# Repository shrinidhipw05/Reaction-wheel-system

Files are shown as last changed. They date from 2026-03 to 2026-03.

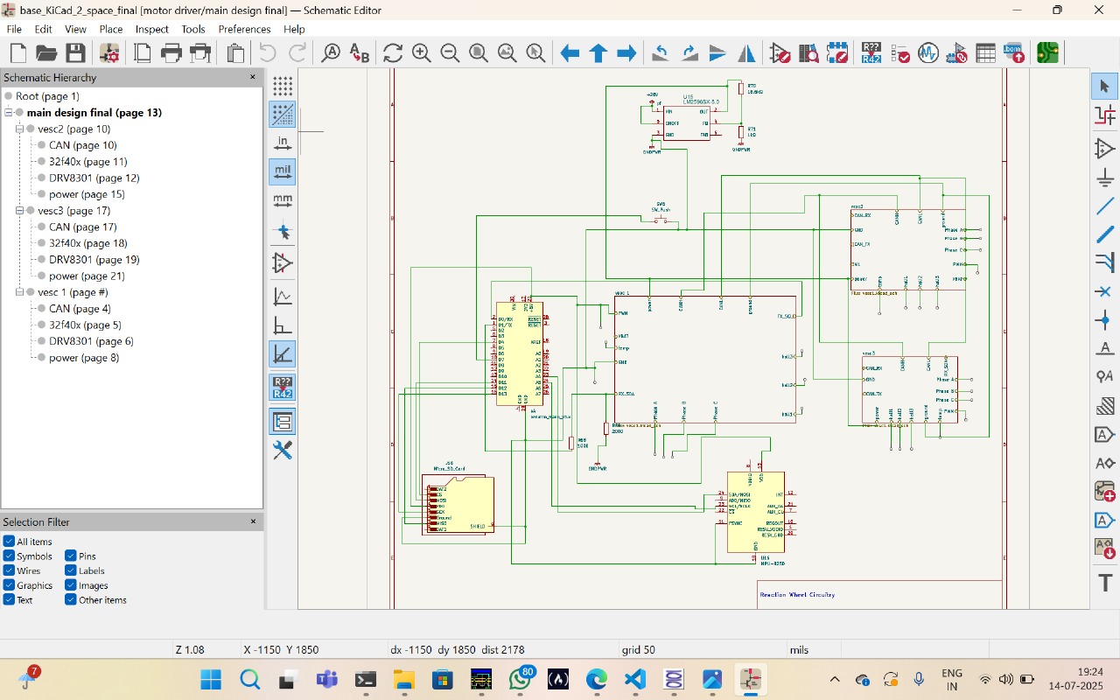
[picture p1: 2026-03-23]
docs & screenshots/Circuit& CAD screenshots/Circuit Schematic .jpg

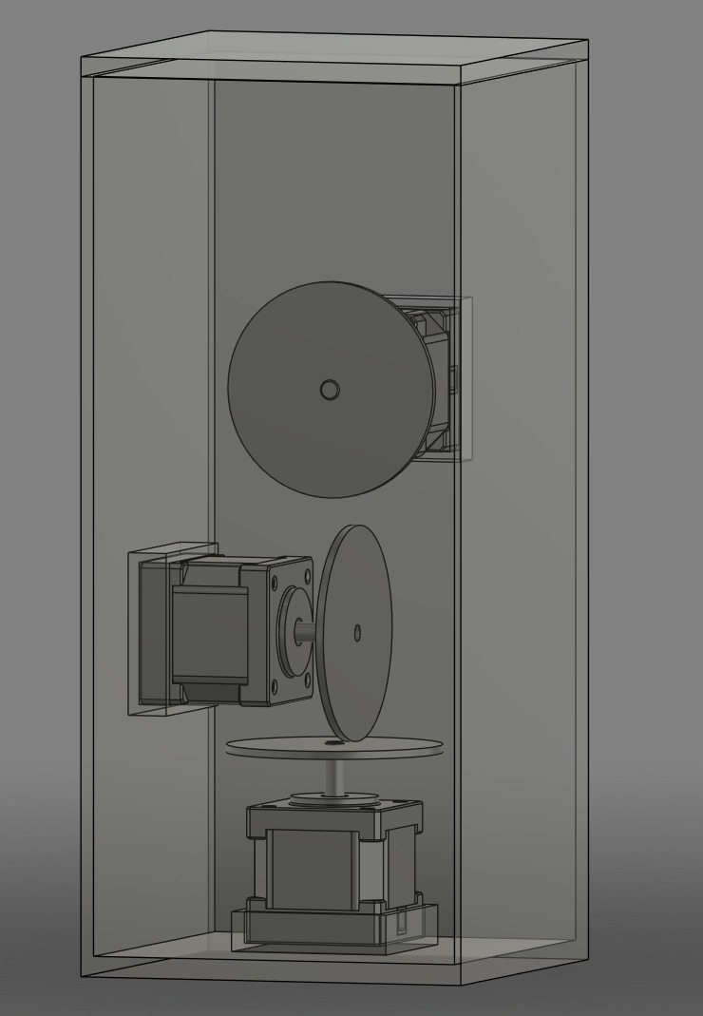
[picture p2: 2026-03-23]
docs & screenshots/Circuit& CAD screenshots/Reaction Wheel tilted front veiw-2.jpg

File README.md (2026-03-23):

# Reaction Wheel-Based CubeSat Attitude Control System

This project implements a **PID-based reaction wheel system** to stabilize the attitude of a CubeSat in space using three BLDC motors driven by VESCs. The system operates autonomously, with real-time data logging up to 24 hours, and includes safety features for thermal and electrical protection. This forms a critical part of satellite attitude control systems used in space missions.

---

## Working Principle & Features

1. **PID Control for Attitude Stabilization** &#x20;
   The system uses real-time PID-based control to stabilize a CubeSat's attitude to a predefined setpoint using three orthogonal reaction wheels (X, Y, Z axes).

2. **Triple BLDC Motor Control** &#x20;
   Each reaction wheel (BLDC motor) is controlled by an individual VESC (Electronic Speed Controller), all interfaced with a central Arduino Nano. The control logic is axis-specific:

   * X-axis: Direct UART connection to Arduino (MASTER)
   * Y, Z axes: Controlled via CAN bus communication from the master VESC

3. **Sensor Fusion Using MPU9250 + Madgwick Filter** &#x20;
   The onboard MPU9250 IMU sensor sends real-time orientation data over I2C to the Arduino Nano. Sensor fusion is performed using the Madgwick algorithm to obtain stable attitude feedback, which is compared against the target setpoint to generate PID corrections.

4. **System Behavior Under Different Conditions**

   * If the CubeSat is misaligned, PID logic drives the respective BLDC motor until the desired setpoint is reached.
   * If the motor temperature exceeds safety thresholds, the VESC automatically slows down or cuts power to prevent damage.
   * The system dynamically adjusts motor RPM in all three axes based on sensor feedback to ensure real-time orientation stability.
   * In the event of communication failure with a secondary VESC (Y or Z), the system continues operating using the X-axis (master) while logging the fault for diagnosis.

5. **VESC Configuration for Safety** &#x20;
   VESCs are configured with:

   * **Temperature Cutoff:**

     * Warning: 80°C
     * Cutoff Start: 80°C
     * Cutoff End: 100°C
   * **RPM, Voltage & Current Limits:** Predefined for safe operation
   * **Auto slowdown & shutdown:** For thermal protection

6. **CAN Communication Between VESCs**

   * VESC 0 (Master): UART enabled, CAN ID = 0, termination resistor enabled
   * VESC 1: UART disabled, CAN ID = 1, termination resistor disabled
   * VESC 2: UART disabled, CAN ID = 2, termination resistor enabled
   * All VESCs must have the following options enabled in VESC Tool:

     * Send CAN Status
     * Multiple VESCs over CAN
     * CAN Forwarding

7. **Real-Time Data Logging** &#x20;
   Data from PID loops, orientation readings, motor RPM, and temperature are logged on an SD card using a MicroSD module via SPI. This enables analysis of system performance over 24 hours.

8. **Manual CSV Reset Feature** &#x20;
   A dedicated push-button on the PCB is implemented to allow manual erasure of the current `.csv` file on the SD card and creation of a new log file. This is useful for resetting data logs between different test sessions without reprogramming or removing the SD card.

---

## Components Used

### Microcontroller

* **Arduino Nano** &#x20;
  Central controller executing PID logic and interfacing with IMU, SD module, and VESCs.

### Sensors

* **MPU9250 (x1)** &#x20;
  9-axis IMU for real-time orientation sensing over I2C.

* **Hall Sensors (x3)** &#x20;
  Built into BLDC motors and connected to VESCs for RPM feedback.

* **NTC 10K Thermistors (x3)** &#x20;
  Glued to BLDC motors and connected to VESCs for temperature monitoring.

### Actuators

* **NEMA17 BLDC Motors (x3)** &#x20;
  Sensored brushless motors used as reaction wheels.

* **VESC (x3)** &#x20;
  Open-source motor controllers, configured via VESC Tool.

### Storage

* **Catalex MicroSD Card Module** &#x20;
  SPI-based SD card module for logging operational data.

---

## How to Setup

Each VESC must be connected to a computer via USB to configure it using the VESC Tool software.

1. **VESC Configuration (via VESC Tool)**

   * Enable:

     * Send CAN Status
     * Multiple VESCs over CAN
     * CAN Forwarding
   * Set CAN IDs:

     * VESC 0: CAN ID = 0, UART = Enabled, Termination Resistor = Enabled
     * VESC 1: CAN ID = 1, UART = Disabled, Termination Resistor = Disabled
     * VESC 2: CAN ID = 2, UART = Disabled, Termination Resistor = Enabled
   * Set Temperature Cutoffs:

     * Warning Temp: 80°C
     * Cutoff Start: 80°C
     * Cutoff End: 100°C

2. **Arduino Setup**

   * Upload the code to Arduino Nano
   * Connect MPU9250 to I2C (A4/A5)
   * Connect SD Module to SPI (D10-D13)
   * Use Software Serial (D8, D9) to connect to VESC UART (x-axis)
   * Ensure CAN communication lines are properly wired between VESC 0 (master), VESC 1, and VESC 2 according to CAN protocol. Use twisted pair wiring for CANH and CANL with proper termination resistors as configured in VESC Tool.

---

## Repository Structure 

```bash
Reaction-Wheel-Controller/
├── src_Task_3/
│   └── src_Task_3.ino                        # Arduino control code
├── README.md                                 # Project documentation
├── hardware_Task_1&2/
│   ├── kicad files opening instructions.pdf  # steps to get kicad_sch & kicad_pcb & kicad_pro files
│   ├── Reaction Wheels Design.step           # CAD model for simulation
│   └── Task-2  .pro , .sch , _pcb files.zip  # zip folder of kicad files
├── Power_Task2_doc/
│   └── Explanation pdf.pdf                   # Power circuit explanation
├── challenges/ 
│   └── challenges.txt                        # Design/implementation difficulties
└── docs & screenshots/
    └── Circuit& CAD screenshots/             # image folders and pdf related to project
    └── VESC_TOOL_Screenshots/
    └── README.pdf                                   
```

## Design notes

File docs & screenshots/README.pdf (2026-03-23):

# Reaction Wheel-Based CubeSat Attitude Control System

### Working Principle & Features

- PID-Based Attitude Stabilization
The CubeSat utilizes a real-time PID control algorithm to stabilize its orientation along three axes (X, Y, Z) using reaction wheels.
- Triple BLDC Motor Configuration
Each axis has a dedicated NEMA17 BLDC motor controlled via a VESC. The X-axis motor is directly managed by the Arduino Nano through UART, while Y and Z axes communicate via CAN bus.
- Sensor Fusion with MPU9250
The IMU provides 9-axis data, processed via the Madgwick filter on the Arduino Nano to derive precise orientation information for PID correction.

### Components Used

- Microcontroller
Arduino Nano acts as the central processor for PID control and communication with peripherals.
- Sensors
- MPU9250: Real-time orientation data via I2C
- Hall Sensors (x3): Built-in RPM feedback from BLDCs
- NTC 10K Thermistors (x3): Temperature monitoring on motors
- Actuators
- NEMA17 BLDC Motors (x3): Sensored motors acting as reaction wheels
- VESCs (x3): Configured motor controllers for precise control
- Storage
Catalex MicroSD Card Module logs operational data via SPI.

### System Behavior & Safety

- Attitude Correction
If misalignment is detected, PID control commands the motors until the orientation matches the setpoint.
- Fault Handling
In case of failure in Y or Z axis VESCs, the X-axis motor continues functioning. Faults

1.

1.

1.

are logged for diagnosis.

- Thermal Protection
VESCs automatically slow down or shut off motors when temperature thresholds are reached:
- Warning: 80°C
- Cutoff Start: 80°C
- Cutoff End: 100°C
- RPM, Voltage & Current Limiting
VESC parameters are configured to prevent overdraw and ensure system safety.

### Communication & Logging

- CAN Communication Setup
- VESC 0 (Master): CAN ID = 0, UART Enabled, Termination = Enabled
- VESC 1: CAN ID = 1, UART Disabled, Termination = Disabled
- VESC 2: CAN ID = 2, UART Disabled, Termination = Enabled

All VESCs have: Send CAN Status, Multiple VESCs, and CAN Forwarding enabled in VESC Tool.

- Real-Time Data Logging
Orientation, PID output, RPM, and temperature are logged for up to 24 hours.
- Manual CSV Reset
A push-button resets the .csv log without reprogramming the SD card.

### Setup Instructions

- Arduino Nano Setup
- Upload PID control firmware
- Connect MPU9250 via I2C (A4/A5)
- Connect SD Module via SPI (D10-D13)
- Connect VESC UART via Software Serial (D8/D9)
- VESC Configuration via USB & VESC Tool
- Set CAN IDs and termination resistors
- Enable CAN features
- Set temperature cutoffs and current/RPM limits
- Wiring Notes
Ensure CANH and CANL lines are twisted pairs with proper termination. Use shielded wires for high-current and signal lines.

1.

1.

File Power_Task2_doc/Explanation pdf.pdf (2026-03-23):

### Reaction Wheel Project: Component Justification, Layout Design, and Power Optimization

### 1. Justification for Choice of Components

NEMA17 BLDC Motor
- Compact size and high torque-to-inertia ratio for precise torque control.
- Supports accurate angular momentum adjustment in small satellites.
- Preferred over brushed DC motors due to better efficiency, longer lifespan, and smoother control without brush wear issues.

VESC (Vedder Electronic Speed Controller)
- Features bi-direction control of BLDC.
- Can be configured via VESC tool, and supports FOC (field oriented control).
- Offers fine torque/speed control and supports UART/CAN with telemetry.

Arduino Nano Microcontroller
- Low-power and compact with sufficient control and communication features.
- Interfaces easily with IMU, VESCs and SD module.

MPU9250 (IMU Sensor)
- Integrates 9-DOF(degrees of freedom) sensing in a low-power chip.
- Provides accurate real-time orientation data.

LM2596 Buck Converter
- High-efficiency step-down converter for voltage regulation.
- Powers both logic and motor components with stability.

### 2. Layout Arrangement

MT60 connectors are used for BLDC phase wires and XT60 for 28V DC input. These connectors ensure secure, high-current connections, suitable for compact and reliable system integration, and can withstand rugged space environment.

Mechanical Layout
- Flywheel Placement: Mounted on the BLDC motor shaft and aligned with the center of mass of the system to minimize unwanted torques.
- Motor and ESC Positioning: VESCs/PCB are placed close to motors to reduce phase wire length.
- Controller and IMU: Positioned near the system center to reduce vibrations and increase accuracy of orientation measurements.

Electrical Layout
- Power Lines: Short, thick wires for power delivery; twisted pairs used to minimize inductive noise.
- PCB Integration: All connections are routed through the custom PCB except for the BLDC motor wires and input DC wires, which are directly soldered onto the PCB for improved current handling and mechanical reliability.

### 3. Strategies for Low Power Consumption

Physical connectors such as MT60 and XT60 also contribute to power efficiency by reducing contact resistance and improving current transfer, thus minimizing power losses at connection points.

Motor Control Efficiency
- Use of Field Oriented Control (FOC) on the VESC to reduce power loss and improve motor efficiency.
- RPM, input voltage, input current, and motor current limits are configured via VESC Tool to prevent excessive power draw and ensure energy-efficient operation.
- The motor automatically slows down at defined temperature cutoff and shuts off at endpoint values set through the VESC Tool, protecting the system and conserving power during thermal stress.

Efficient Power Conversion
- LM2596 chosen for its high-efficiency conversion (up to 85%).
- Voltage levels chosen to match component requirements precisely, avoiding unnecessary conversion losses.

Minimized Communication Overhead
- Use of UART/CAN instead of high-power wireless communication modules.
- Efficient, lightweight data protocols for communication between Arduino and VESC.

THIS APPROACH ENSURES THAT THE REACTION WHEEL SYSTEM REMAINS COMPACT, EFFICIENT, AND RELIABLE—KEY CHARACTERISTICS FOR SPACE-CONSTRAINED, POWER-LIMITED ENVIRONMENTS LIKE SATELLITES OR SPACECRAFT.

NEXT PAGE CONTAINS THE REACTION WHEEL BLOCK DIAGRAM INDICATING COMMUNICATION TYPE AND POWER DISTRIBUTION AMONG THE COMPONENTS OF THE PCB.

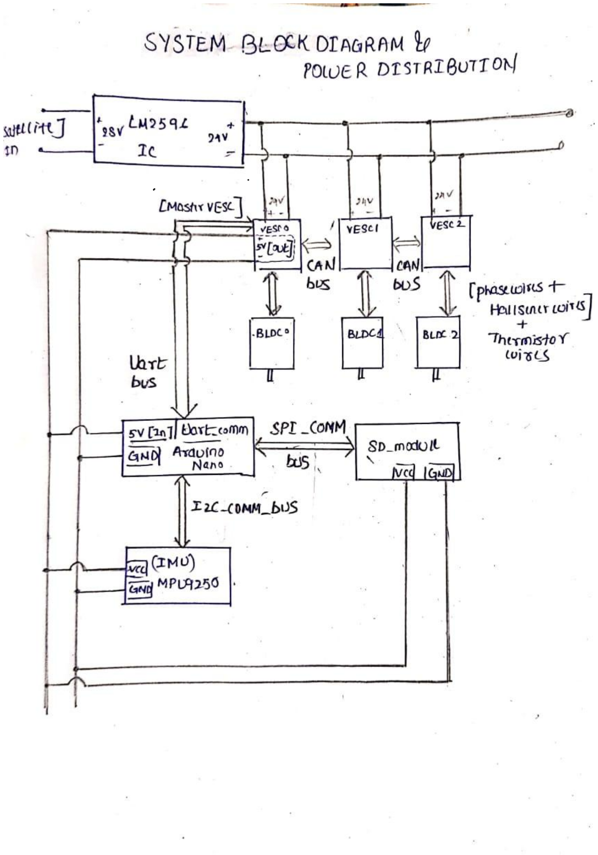
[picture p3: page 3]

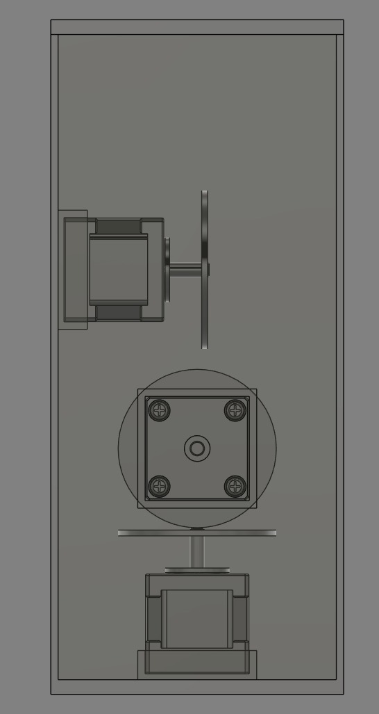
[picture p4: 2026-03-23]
docs & screenshots/Circuit& CAD screenshots/Reaction Wheel Side View.jpg

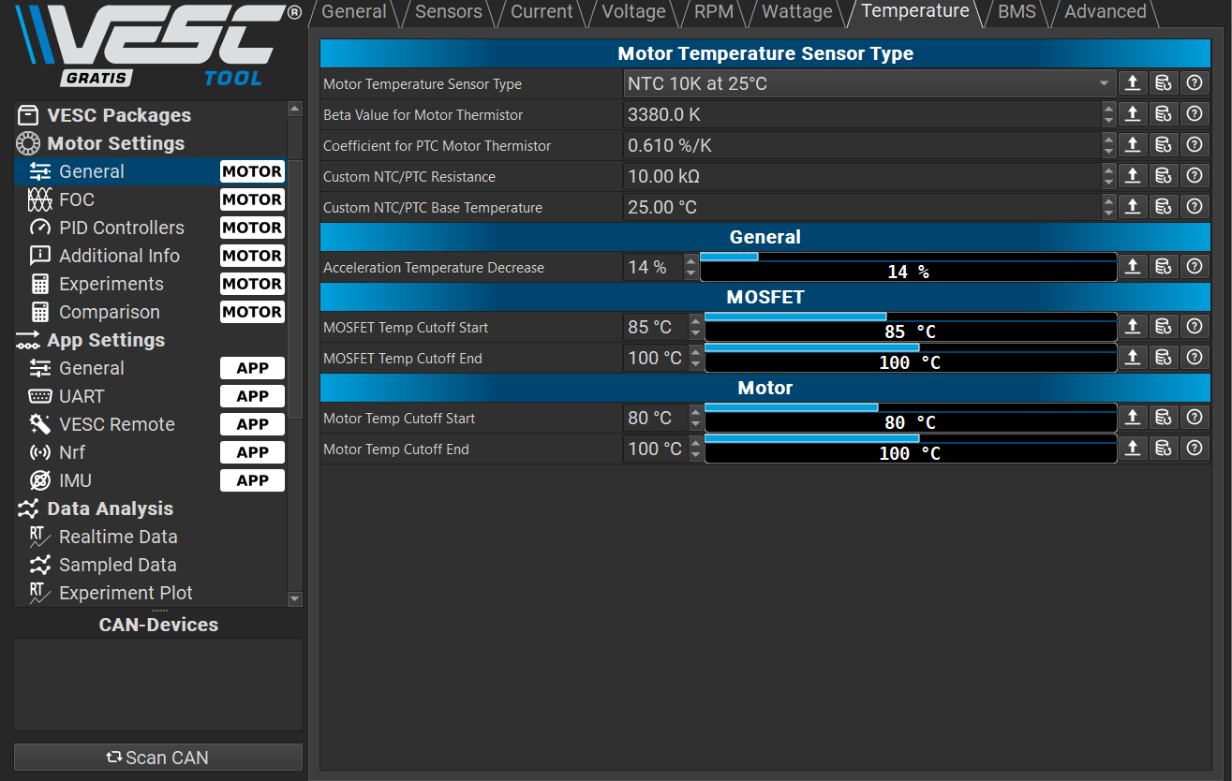
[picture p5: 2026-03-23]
docs & screenshots/VESC_TOOL_Screenshots/vesc_motor_temperature.png

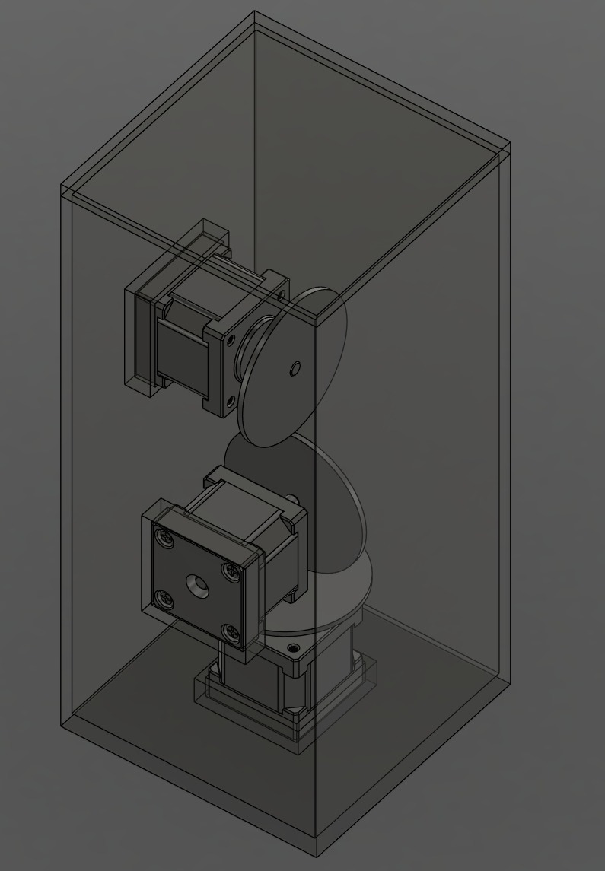
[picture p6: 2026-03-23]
docs & screenshots/Circuit& CAD screenshots/Reacition Wheel Isometric view.jpg

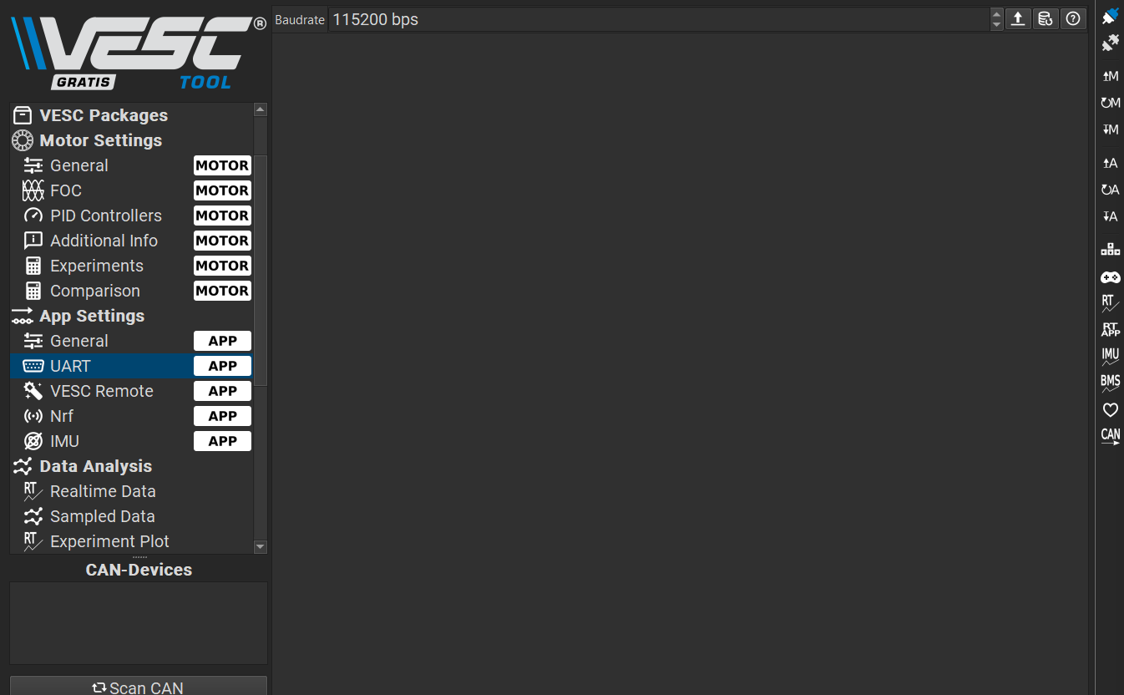
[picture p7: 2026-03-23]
docs & screenshots/VESC_TOOL_Screenshots/vesc_app_Uart.png

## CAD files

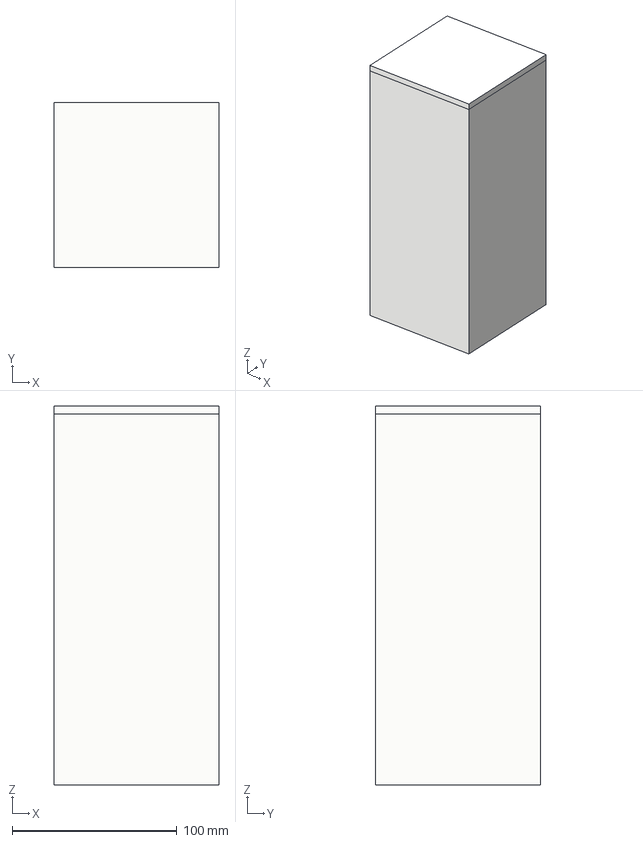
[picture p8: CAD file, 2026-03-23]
hardware_Task 1&2/Reaction Wheels Design.step
100.0 x 100.0 x 230.0 mm
Satellite Housing
6627T38_Stepper Motor x 3
Wheel1
Wheel2
Wheel3
Housing Lid

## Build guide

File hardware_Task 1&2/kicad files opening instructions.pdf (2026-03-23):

- The main kicad files for this project are named as:
1. motor driver.kicad_pro
2. motor driver.kicad_sch
3. motor driver.kicad_pcb
- The KICAD file of this project includes, custom library and is hierarchal with respect to schematic file, hence the folder contains the multiple files with the main project’s kicad files.
- To access above main files:
1. Unzip the folder-“ Task-2 .pro , .sch , _pcb files” and open it.
2. the folder contains a single subfolder, open that.
3. after opening:

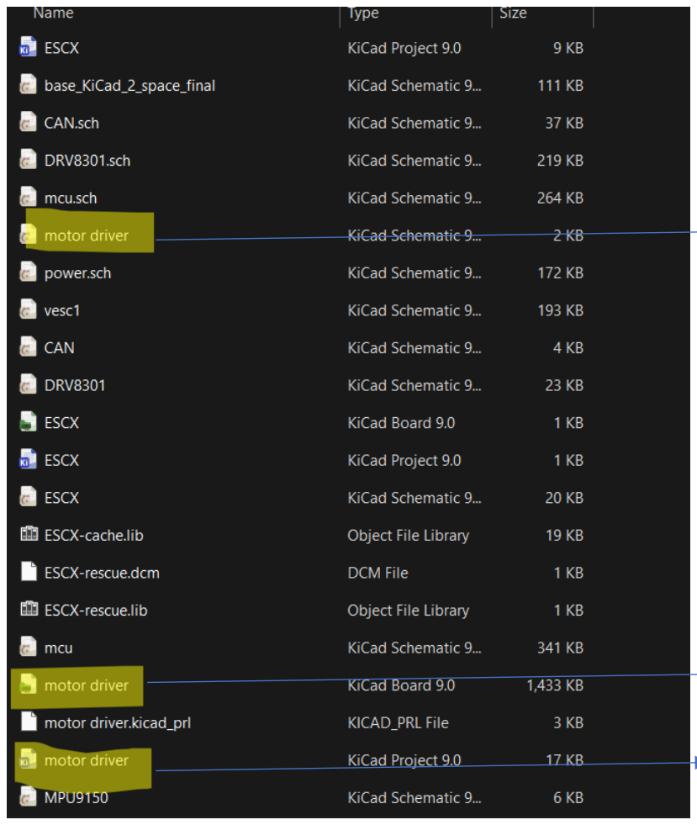
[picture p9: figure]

Click on this to view the circuit schematic (motor driver.kicad_sch)

Click on this to view the circuit pcb footprint (motor driver .kicad_pcb)

Click on this to view the circuit kicad project file (includes all files, motor driver.kicad_pro)

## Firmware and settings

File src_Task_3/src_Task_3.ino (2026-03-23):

//include all mandatory external modules for code's operation 
#include <VescUart.h>
#include <Wire.h>
#include <MPU9250.h>
#include <MadgwickAHRS.h>
#include <SoftwareSerial.h>
#include <SD.h>

// MPU9250 and Madgwick filter setup.
MPU9250 mpu;
Madgwick filter;
float roll = 0.0, pitch = 0.0, yaw = 0.0;

// VESC and Uart communication setup.
VescUart vesc;
#define RX_PIN 10
#define TX_PIN 11
SoftwareSerial vescSerial(RX_PIN, TX_PIN);

// SD Card ,logfile setup
#define SD_CS 4  //declaring chip select for the arduino .
File logfile;

// Manual data flushing : Reset Button for SD file (active LOW).
#define RESET_BUTTON 7

// PID parameters
float kp = 1.2f, ki = 0.5f, kd = 0.1f;
float setpoint[3] = {0.0f, 0.0f, 0.0f}; // Roll, Pitch, Yaw (target).
float integral[3] = {0.0f, 0.0f, 0.0f}, prev_error[3] = {0.0f, 0.0f, 0.0f};
unsigned long prev_time = 0;

// Anti-windup limits for integral term
const float INTEGRAL_LIMIT = 5000.0f; // tune this to your system

// Minimum acceptable dt (seconds)
const float MIN_DT = 0.0001f; // 0.1 ms - prevents divide-by-zero and huge derivative

// VESC telemetry buffer, storing critical data of VESC and its corresponding BLDC.
struct VESCData {
  float rpm;
  float Dutycycle;
  float energy_consumed;
  float VESC_temp;
  float Motor_temp;
  float inputVoltage;
  float Motor_current;
};
VESCData vescTelemetry[3];   //Three buffers for three VESCs.

//uint32_t : 32bit(4 byte) unsigned integer
const uint32_t MAX_FILE_SIZE = 1024UL * 1024UL * 1024UL; // 1 GB for 24-hour logging.

void setup() {
  Serial.begin(115200);
  vescSerial.begin(115200);             // VESC_x and Arduino Uart connection setup.
  vesc.setSerialPort(&vescSerial);      // VESC setup.
  Wire.begin();
  if (!mpu.setup(0x68)) {
    Serial.println("MPU setup failed!");
    // proceed but IMU updates won't occur; handle as needed
  }
  delay(1000);
  filter.begin(100);                    // 100 Hz sample rate, filter setup.

  pinMode(RESET_BUTTON, INPUT_PULLUP);  // setup flush button for the logfile.

  if (!SD.begin(SD_CS)) {
    Serial.println("SD Card init failed!");
    // block here so you notice the storage issue
    while (1);
  }
  Serial.println("SD Card init successful.");

  initializeLogFile();

  // Important: initialize prev_time to current millis to avoid huge dt on first loop.
  prev_time = millis();
}

// logfile initializing funtion, call period-24 hours,can be called manually via reset button.
// deletes existing file and creates a new logfile. 
void initializeLogFile() {
  if (SD.exists("log.csv")) {
    SD.remove("log.csv");
    Serial.println("Old log file deleted.");
  }
  logfile = SD.open("log.csv", FILE_WRITE);
  if (logfile) {
    logfile.println("TIME(ms),ROLL(°),PITCH(°),YAW(°),SET_ROLL(°),SET_PITCH(°),SET_YAW(°),DUTY_X,ENERGY_X(Wh),RPM_X,VESC_X_TEMP(°C),MOTOR_X_TEMP(°C),VOLTAGE_X_IN,MOTOR_X_CURRENT,DUTY_Y,ENERGY_Y(Wh),RPM_Y,VESC_Y_TEMP(°C),MOTOR_Y_TEMP(°C),VOLTAGE_Y_IN,MOTOR_Y_CURRENT,DUTY_Z,ENERGY_Z(Wh),RPM_Z,VESC_Z_TEMP(°C),MOTOR_Z_TEMP(°C),VOLTAGE_Z_IN,MOTOR_Z_CURRENT");
    logfile.close();
  } else {
    Serial.println("Failed to create log.csv header.");
  }
}

// funtion for reading satellite attitude and filtering.
//stores the value in variables-(roll,pitch,yaw) .
void readOrientation() {
  if (mpu.update()) {
    filter.update(
      mpu.getGyroX(), mpu.getGyroY(), mpu.getGyroZ(),
      mpu.getAccX(), mpu.getAccY(), mpu.getAccZ(),
      mpu.getMagX(), mpu.getMagY(), mpu.getMagZ()
    );
    roll = filter.getRoll();
    pitch = filter.getPitch();
    yaw = filter.getYaw();
  }
}

//function for computing PID-based signal to VESC.
//formula for output control signal- "u(t) = kp * error + ki * integral + kd * derivative".
// integral and prev_error are passed by reference so they update the arrays in-place.
float computePID(float setpoint_val, float current, float &integral_ref, float &prev_error_ref, float dt) {
  if (dt < MIN_DT) dt = MIN_DT; // safety clamp
  float error = setpoint_val - current;

  // integrate with anti-windup (clamp integral)
  integral_ref += error * dt;
  if (integral_ref > INTEGRAL_LIMIT) integral_ref = INTEGRAL_LIMIT;
  else if (integral_ref < -INTEGRAL_LIMIT) integral_ref = -INTEGRAL_LIMIT;

  float derivative = (error - prev_error_ref) / dt;
  prev_error_ref = error;

  float output = kp * error + ki * integral_ref + kd * derivative;
  return output;
}

//function setting the motor RPM(via computePID funtion) corresponding to input axis.
//canID - ( VESC_X(master) = 0 , VESC_Y = 1 , VESC_Z = 2 ) .
//if axis=0, command is sent via Uart else, command is sent to master and then master forwards to VESC based on the INPUT CAN_id .
void controlAxis(int axis, float current_angle, float dt) {
  if (dt < MIN_DT) return; // safety, though computePID also handles it

  float control = computePID(setpoint[axis], current_angle, integral[axis], prev_error[axis], dt);
  int rpm = constrain((int)(control * 100.0f), -4000, 4000); // Scale and clamp to VESC rpm range.

  if (axis == 0) {
    vesc.setRPM(rpm);
  } else {
    sendCANCommand(axis, rpm);
  }
}

//funtion to send COMM_SET_RPM command to desired VESC via master over CAN.
void sendCANCommand(uint8_t id, int rpm) {
  COMM_PACKET_ID command_id = COMM_SET_RPM; // command type .
  uint8_t payload[5];
  payload[0] = id;
  int32_t rpm_val = (int32_t)rpm;
  // Big-endian packing (match your master firmware expectations)
  payload[1] = (rpm_val >> 24) & 0xFF;
  payload[2] = (rpm_val >> 16) & 0xFF;
  payload[3] = (rpm_val >> 8) & 0xFF;
  payload[4] = rpm_val & 0xFF;
  vesc.sendPacket(command_id, payload, 5);  // send command and data via CAN.
}

//funtion for retrieving the real time data from VESC and its motor over CAN and then storing it in telemetry buffer and also printing onto serial moniter. 
void requestCANValues(uint8_t can_id) {
  uint8_t payload[2];
  payload[0] = can_id;
  payload[1] = COMM_GET_VALUES;
  vesc.sendPacket(COMM_FORWARD_CAN, payload, 2);    //sending request for retrieving data over CAN ..

  delay(10); // small wait for response; increase if necessary on slow bus

  if (vesc.getVescValues()) {
    // protect index range
    if (can_id < 3) {
      vescTelemetry[can_id].rpm = vesc.data.rpm;
      vescTelemetry[can_id].Dutycycle = vesc.data.dutyCycleNow;
      vescTelemetry[can_id].energy_consumed = vesc.data.wattHours;
      vescTelemetry[can_id].VESC_temp = vesc.data.tempMosfet;
      vescTelemetry[can_id].Motor_temp = vesc.data.tempMotor;
      vescTelemetry[can_id].inputVoltage = vesc.data.inpVoltage;
      vescTelemetry[can_id].Motor_current = vesc.data.currentMotor;
    }

    char axis = (can_id == 0) ? 'X' : (can_id == 1) ? 'Y' : (can_id == 2) ? 'Z' : '?';
    Serial.print("[VESC "); Serial.print(axis); Serial.print("] RPM: "); Serial.print(vesc.data.rpm);
    Serial.print(" | Duty Cycle: "); Serial.print(vesc.data.dutyCycleNow);
    Serial.print(" | Energy consumed: "); Serial.print(vesc.data.wattHours);
    Serial.print(" | VESC Temp: "); Serial.print(vesc.data.tempMosfet);
    Serial.print(" | Motor Temp: "); Serial.print(vesc.data.tempMotor);
    Serial.print(" | Input Voltage: "); Serial.print(vesc.data.inpVoltage);
    Serial.print(" | Motor Current: "); Serial.println(vesc.data.currentMotor);
  } else {
    // No response / parse failed - it's helpful to know occasionally
    // Serial.println("No VESC values parsed for CAN id " + String(can_id));
  }
}

// funtion for logging data , storing the contents of buffer in .csv file, and flushing data.
void logData() {
  if (digitalRead(RESET_BUTTON) == LOW) {
    Serial.println("Reset button pressed — wiping log file.");
    initializeLogFile();
    delay(500);
    return;
  }

  // Safe file-size check (open read-only, check size, close)
  File f = SD.open("log.csv", FILE_READ);
  if (f) {
    uint32_t size = f.size();
    f.close();
    if (size > MAX_FILE_SIZE) {
      Serial.println("Max file size reached — auto wiping log file.");
      initializeLogFile();
      return;
    }
  }

  logfile = SD.open("log.csv", FILE_WRITE);
  if (logfile) {
    logfile.print(millis()); logfile.print(",");
    logfile.print(roll); logfile.print(",");
    logfile.print(pitch); logfile.print(",");
    logfile.print(yaw); logfile.print(",");
    logfile.print(setpoint[0]); logfile.print(",");
    logfile.print(setpoint[1]); logfile.print(",");
    logfile.print(setpoint[2]); logfile.print(",");

    for (int i = 0; i < 3; i++) {
      logfile.print(vescTelemetry[i].Dutycycle); logfile.print(",");
      logfile.print(vescTelemetry[i].energy_consumed); logfile.print(",");
      logfile.print(vescTelemetry[i].rpm); logfile.print(",");
      logfile.print(vescTelemetry[i].VESC_temp); logfile.print(",");
      logfile.print(vescTelemetry[i].Motor_temp); logfile.print(",");
      logfile.print(vescTelemetry[i].inputVoltage); logfile.print(",");
      logfile.print(vescTelemetry[i].Motor_current);
      if (i < 2) logfile.print(",");
    }
    logfile.println();
    logfile.close();
  } else {
    Serial.println("SD write failed! Possibly card full or corrupted.");
  }
}

void loop() {
  // Compute dt once per loop (consistent for all axes)
  unsigned long now = millis();
  float dt = (now - prev_time) / 1000.0f;
  if (dt <= 0.0f) {
    // if clock moved backward or prev_time uninitialized, reset prev_time and skip this loop
    prev_time = now;
    return;
  }

  // Read sensors and update orientation
  readOrientation();

  // Control each axis using the same dt
  controlAxis(0, roll, dt);   // ROLL
  controlAxis(1, pitch, dt);  // PITCH
  controlAxis(2, yaw, dt);    // YAW

  // Request telemetry (can be staggered if bus is busy)
  requestCANValues(0);
  requestCANValues(1);
  requestCANValues(2);

  // Log data
  logData();

  // Update prev_time for next loop
  prev_time = now;

  // Short delay - tune as necessary. Keep in mind dt accounts for real elapsed time.
  delay(10);
}
